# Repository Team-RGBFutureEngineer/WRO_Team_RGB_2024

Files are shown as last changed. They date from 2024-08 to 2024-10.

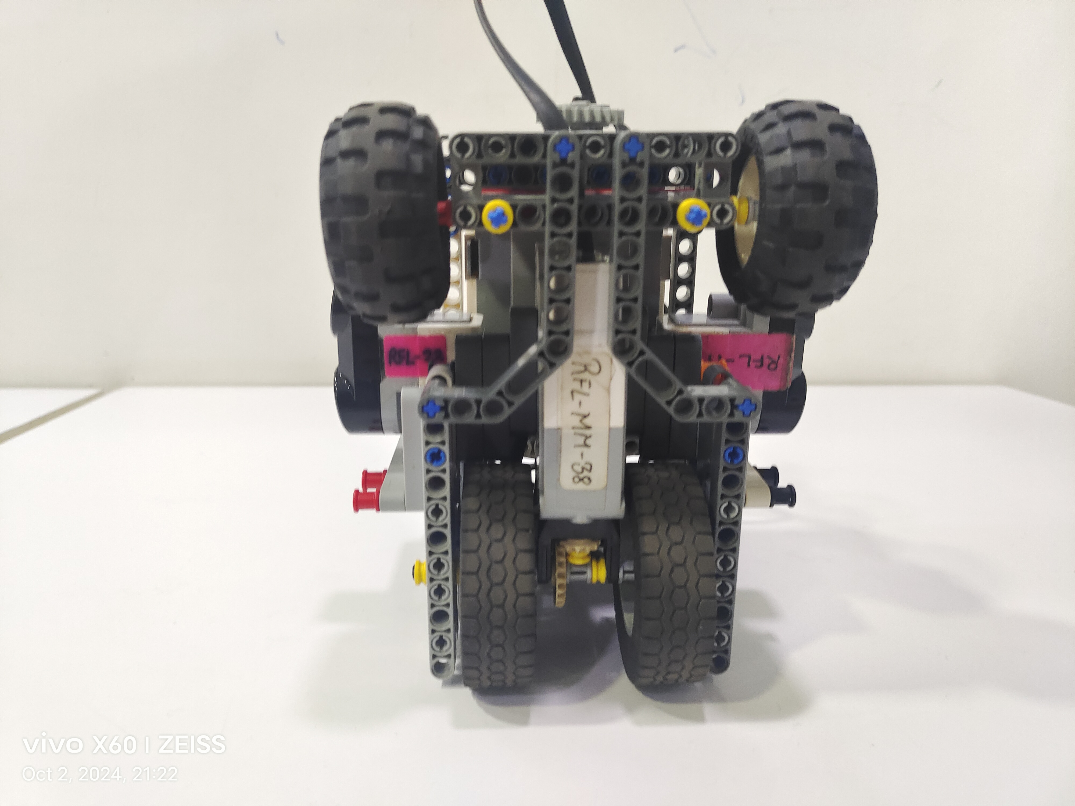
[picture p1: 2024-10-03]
v-photos/BOTTOM.jpg

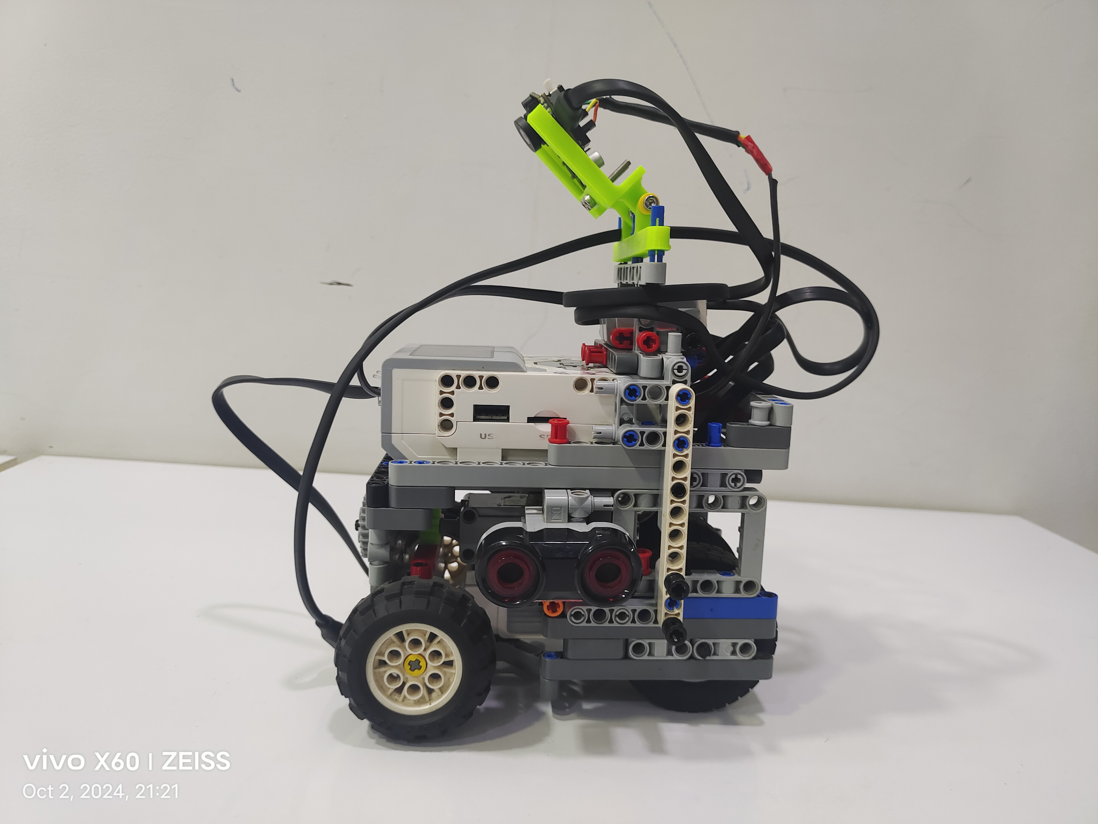
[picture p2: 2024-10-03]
v-photos/LEFT.jpg

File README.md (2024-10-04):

# Team RGB – WRO Future Engineers 2024

We are **Team RGB**, a duo of engineering students from **RFL Academy**, united by our passion for **Robotics**. We have clearly divided our roles to maximize our strengths:

**Bhavya Sanghrajka – Lead Programmer & Electronics**: Bhavya is responsible for the robot's programming and electronics systems. He specializes in developing advanced control algorithms, including PID control, and designing the logic that powers the robot’s movements and decision-making. Bhavya ensures the seamless integration of sensors and motors, programming the robot to execute precise maneuvers for both the open-round and obstacle-round. 

**Raj Kothari – Lead Designer & Constructor**: Raj is responsible for the structural and mechanical design of the robot. With a focus on precision and functionality, he uses CAD software to create a robust and lightweight design that adheres to the competition’s strict dimension and weight restrictions. Raj specializes in optimizing the integration of LEGO components with custom-designed parts, ensuring the robot performs reliably in both maneuverability and stability under competition conditions.

**Sahil Gajera - Mentor**:  A computer engineer by profession, Sahil sir is a robotics and linux enthusiast. His experience in First Robotics Competition (FRC) has helped us a lot in this entire joureny of Future Engineer category. 

# Construction Timeline

## First Iteration

Iteration 1

In the **Initial phase** of our design, we prioritized selecting lightweight yet durable components to ensure the robot maintained an optimal balance between strength and weight. Our first iteration featured a **3D-printed chassis** combined with a **steering mechanism** constructed from **LEGO parts**. However, this design presented several limitations, as the integration of the LEGO components with the 3D-printed chassis proved unreliable, and the overall structure became too bulky and heavy.

**Strengths**
- **Lightweight and Durable Focus** - Prioritizing lightweight yet durable components ensured that the robot had an optimal balance between strength and weight, which is essential for performance.
- **Customization Options** - Using a 3D-printed chassis allowed for high levels of customization, enabling us to explore innovative design possibilities.

**Weakness**
- **Structural Instability** - Integration of LEGO components with 3D-printed parts lacked mechanical stability, leading to weak points in the structure.
- **Bulky Design** - The overall structure became too bulky and heavy, which negated the initial focus on lightweight components.

**Opportunities**
- **Material Optimization** - Explore alternative 3D printing materials or geometries (e.g., honeycomb structures) to reduce weight without compromising durability.
- **Enhanced Modular Design** - Refining the integration of modular components (e.g., steering mechanisms) could improve adaptability and reduce structural issues in future iterations.

**Threats**
- **Performance Limitations** - The bulky and unreliable design could limit the robot’s performance, particularly in speed, maneuverability, and battery efficiency.
- **Time and Resource Constraints** - Continuous redesigns or modifications to address the weaknesses could impact project timelines and require additional resources.

## Second Iteration

Iteration 2

For the **Second iteration**, we transitioned to a **fully 3D-printed design**, including the steering mechanism. This solved many of the issues encountered in the previous version. The meshing of the **3D-printed gears** and steering components was precise. However, we faced challenges in aligning some parts during assembly, and reprinting components was **time-consuming** when adjustments were needed.

**Strengths**
- **Fully 3D-Printed Design** - Transitioning to a fully 3D-printed design, including the steering mechanism, resolved many integration issues from the previous iteration.
- **Precision in Gear Meshing** - Full control over gear design allowed for highly accurate meshing between 3D-printed gears and steering components, minimizing backlash and increasing mechanical efficiency.

**Weakness**
- **Assembly Complexity** - Alignment challenges arose during assembly, as 3D-printed components lacked built-in tolerances, making precise fitting of parts difficult.
- **Reprinting Delays** - Adjustments or design modifications required lengthy reprints, which increased downtime and reduced iteration speed.

**Opportunities**
- **Improved Assembly Process** - Refining the design for easier alignment during assembly could streamline the building process and reduce errors.
- **Iterative Refinement** - With continued iterations, the 3D-printed design could become more efficient and quicker to produce, especially by fine-tuning the parts for better fit.

**Threats**
- **Time Constraints** - The need to frequently reprint parts for adjustments could significantly impact project timelines, especially if iterations are slow.
- **Dimensional Inaccuracies** - Printer calibration or material expansion during cooling could lead to dimensional inaccuracies, affecting part performance and requiring reprints.

## Final Iteration

LEGO CAD

In the **Third iteration**, we opted for a **fully LEGO-based chassis**. Given that we had already achieved a precise gear mesh using custom **3D-printed gears and racks**, we integrated these components into the new design. The rear wheel motor relied on LEGO gears, while the steering mechanism utilized a custom 3D-printed gear perfectly matched with a custom 3D-printed rack, offering the best combination of customization and reliability.

**Strengths**
- **Fully 3D-Printed Design** - Transitioning to a fully 3D-printed design, including the steering mechanism, resolved many integration issues from the previous iteration.
- **Precision Gear Integration** - The combination of custom 3D-printed gears and racks with LEGO components resulted in highly precise gear meshing, minimizing mechanical losses and maximizing drive efficiency.

**Weakness**
- **Design Flexibility Limitations** - While the LEGO chassis offered modularity, it imposed constraints on component arrangement and customization compared to a fully 3D-printed or custom design.
- **Potential Compatibility Issues** - Integrating 3D-printed components with LEGO parts introduced potential alignment and mechanical fit challenges that could affect reliability over time.

**Opportunities**
- **Hybrid System Optimization** - Further optimization of the hybrid LEGO-3D printed design could lead to increased system robustness, combining the strengths of both approaches (e.g., modularity of LEGO, precision of custom parts).
- **Enhanced Design Modularity** - Expand modularity by developing interchangeable 3D-printed parts compatible with LEGO, facilitating quick upgrades or repairs without major redesigns.

**Threats**
- **Component Wear and Tear** - Over time, the wear on LEGO gears and 3D-printed parts could affect performance, requiring maintenance or replacement of key components.
- **Structural Limitations** - LEGO's inherent structural limitations could impact the robot's ability to handle heavy loads or more demanding tasks, potentially hindering further scaling or robustness improvements.

# Custom 3D Printed Parts
## Rack & Gear
rack
gear

We designed a **custom 7.2 cm rack** with a similar **groove** pattern and design as the standard **6.4 cm LEGO rack**. The original 6.4 cm LEGO rack had some problems wherein its shorter length made it difficult to mesh smoothly with the **20-tooth double bevel black LEGO gear**, which restricted the wheels from achieving specific steering angles.

However, even with our 7.2 cm rack, we encountered a minor issue: the grooves of the black LEGO gear and our custom rack weren’t perfectly meshing. While it functioned temporarily, the meshing wasn't ideal, and the **error compounded by 0.01 with each turn**. To overcome this, we also created a **custom 12 tooth gear** whose grooves are **perfectly meshing** with custom rack thus eliminating meshing errors and significantly improved the accuracy of the steering, allowing the wheels to turn at **precise angles**.

**Strengths**
- **Improved Rack Design** - The custom 7.2 cm rack, designed to replicate the LEGO rack's groove pattern, provided better meshing with the LEGO gear, reducing initial steering issues and improving maneuverability.
- **Enhanced Steering Precision** - The development of a custom 12-tooth gear that perfectly meshed with the custom rack eliminated alignment issues, significantly improving the steering accuracy and control.

**Weakness**
- **Initial Misalignment Issues** - Despite the improvement with the custom rack, the minor alignment issue between the grooves of the LEGO gear and custom rack introduced a small cumulative error (0.01 degrees), which reduced precision over time.
- **Complex Manufacturing** - The creation of custom racks and gears requires precision manufacturing (likely 3D printing), which can be time-consuming and requires access to specialized equipment for accurate results.

**Opportunities**
- **Optimized Custom Components** - Further refinement of custom components, such as varying tooth profiles or gear materials, could increase durability, precision, and overall performance in steering and navigation systems.

**Threats**
- **Component Wear and Tear** - Over time, custom 3D-printed components may wear down faster than standard LEGO parts, introducing alignment or meshing issues, which could degrade steering accuracy.
- **Component Compatibility** - Relying on custom gears and racks introduces the risk of incompatibility with other standard LEGO components, potentially limiting future upgrades or repairs using off-the-shelf LEGO parts.

## Pixy Mount & Beam
pixy mount and beam

During the robot’s journey, we encountered **instability with the Pixy camera**, which frequently shifted and struggled to accurately detect objects. To address this issue and secure the Pixy at a precise angle, we 3D-printed two custom components.

First, we created a **custom beam** that perfectly aligned with the **holes of the H-frame**, enabling us to securely attach the Pixy to the connector. Additionally, we designed a **custom mount** to provide further support and stability for the Pixy camera.

Both the beam and the Pixy mount were connected using **3 mm screws**, allowing for easy adjustment and locking of the camera at the **desired angle**. This setup ensured that the Pixy could consistently scan and detect objects with accuracy, especially during the obstacle round challenge.

**Strengths**
- **Improved Camera Stability** - The custom 3D-printed beam and mount provided secure, adjustable positioning for the Pixy camera, ensuring accurate object detection and eliminating the instability encountered during movement.
- **Precise Alignment** - The beam design was tailored to align perfectly with the holes of the H-frame, facilitating a secure connection and stable support for the Pixy, improving its performance during the obstacle challenge.

**Weakness**
- **Complex Assembly** - The custom setup, involving 3 mm screws and custom components, added complexity to the assembly process and may require careful calibration to achieve the optimal camera angle.
- **Potential Adjustability Limitations** - While the camera can be adjusted, any significant design changes in future iterations may require reprinting the custom components, introducing delays in development.

**Opportunities**
- **Modular Design Improvements** - Refining the 3D-printed mount and beam to be modular or flexible could allow for easier adjustments, enabling the camera to adapt to different angles or robot configurations.
- **Enhanced Object Detection** - The secure and precise positioning of the Pixy camera opens the possibility for improved computer vision or AI-driven detection algorithms, leading to better object recognition and navigation accuracy.

**Threats**
- **Component Durability** - Over time, the 3D-printed beam and mount may experience wear, especially if frequent adjustments are made, potentially leading to loosening or misalignment that affects detection accuracy.

## Our Robot

lego with dimensions

Our robot measures **16.5 cm in length, 16 cm in width, and 24 cm in height**, with a total weight of **0.9 kg**. It is powered by **two medium motors**—one dedicated to driving the rear wheels and the other for controlling the steering mechanism. The rear wheels (62.4 x 20s) are mounted on a **single axle** and connected to the motor via LEGO gears. The steering wheels (62.3 x 21s) are also mounted on a single axle and connected to the motor, with the steering system operating through the custom 3D-printed gear and rack, ensuring smooth and precise movement.

The robot is equipped with two **LEGO ultrasonic sensors**, mounted on both left & right side, and a **gyro sensor** placed on top for navigation. For obstacle detection, we integrated a **Pixy 2.1 camera**. The entire system is powered by a **LEGO Mindstorms EV3 brick**, which manages the control and coordination of the sensors and motors. 

- **Turning Radius of our robot is 75 degree**
- **Centre Distance between both wheels is 11 cm** 

# Electricals 

Robot Schematic

This diagram illustrates the wiring and components configuration of our robot 

### Central Unit
EV3 Brick
### Input Ports (1-4)
- **Port 1: Left LEGO Ultrasonic Sensor**
- **Port 2: Right LEGO Ultrasonic Sensor**
- **Port 3: Gyro Sensor**
- **Port 4: Pixy Camera**
### Output Ports (A-D)
- **Port A: Rear Wheel Motor**
- **Port B: Steering Wheel Motor**

# Power Management

LEGO DC BATTERY

This is our 2050 mA DC Rechargeable Battery which provides power to the EV3 Brick and other components. Here's an estimated power consumption breakdown for each component:

**1. LEGO Ultrasonic Sensor:**
- Current Consumption: Approximately **20 mA**
- Power Consumption: Approximately **0.2W**

**2. LEGO Medium Motor:**
- Current Consumption: Between **100-150 mA** 
- Power Consumption: Approximately **1.25W**
  
**3. LEGO Gyro Sensor:**
- Current Consumption: Approximately **10-15 mA**
- Power Consumption: Approximately **0.15W**
  
**4. LEGO EV3 Brick:**
- Current Consumption: Between **150-250 mA**
- Power Consumption: Approximately **2W**
  
**5. Pixy 2.1 Camera:**
- Current Consumption: Approximately **140 mA**
- Power Consumption: Approximately **1.4W**

graph

# Components

Our bot consists of the following components:
- LEGO Mindstorm EV3 Brick
- LEGO Rechargeable DC Battery
- EV3 Medium Servo Motor
- LEGO Ultrasonic Sensors
- LEGO Gyro Sensor
- PIXY 2.1 Camera
- Lego Cables
- Russian Wheels
- Steering Wheels
### 1. LEGO Mindstorm EV3 Brick
The EV3 Brick is the central control unit of our robot. It features a programmable interface with a display screen and buttons for manual control. It is programmed using LEGO's Mindstorm software. It has 4 ports for Input and output, currently, our bot uses 2 output ports for both medium motors and 3 input ports for 2 ultrasonic sensors and gyro sensors.

### 2. LEGO Rechargeable DC Battery
This 2000 mAh battery provides power to the EV3 Brick and other components. It is rechargeable and designed to fit into the EV3 Brick.

### 3. EV3 Medium Servo Motor
The medium servo motor is used for precise movements and rotations. It is smaller in size compared to the large motor and is capable of rotating 360 degrees with precise angle control, useful for the steering mechanism.

### 4. LEGO Ultrasonic Sensors
The sensors are mounted on both sides of the robot to accurately measure the proximity to adjacent walls. The sensor then measures the round-trip time for the reflected waves to return. By calculating the time interval between emission and reception, the sensor determines the distance between the robot and the wall using the speed of sound in air as a constant.

### 5. LEGO Gyro Sensor
The sensor is mounted on the top of the robot, it enables precise control over the robot's orientation adjustments and stability by detecting minute changes in angular displacement. It plays an essential role in trajectory tracking by calculating and storing the robot’s initial position. Over the course of three laps, the gyro ensures that the robot consistently returns to its starting position.

### 6. Pixy 2.1 Camera
The PIXY 2.1 Camera is an advanced vision sensor that can detect and track objects based on color. It provides real-time image processing capabilities and is used for object detection in obstacle challenge.

### 7. LEGO Cables
These cables help in building connections between motors, and sensors to the EV3 Brick. They are responsible for transmitting power and data between the components and EV3 Brick.

### 8. LEGO Russian Wheels (62.4 x 20)
These wheels are used as rear wheels in our robot. These wheels are 62.4 mm in diameter and 20 mm in width.

### 9. LEGO Tractor Wheels (56 x 26)
These wheels are used as front wheels in our robot. These wheels are 56 mm in diameter and 26 mm in width.

# Programming Timeline
During the initial two iterations of our robot, we utilized a 3D-printed chassis to allow for greater customization and explore new design possibilities. For processing and control, we opted to use a Raspberry Pi, despite it being our first time working with this platform, including its schematics and programming interface.

To streamline our workflow, we researched methods for accessing and controlling the **Raspberry Pi** without the need for external peripherals like a monitor or keyboard. We initially implemented **RealVNC Viewer**, a software solution that enabled remote access to the Raspberry Pi from the development computer. However, we soon encountered performance limitations, as the virtual environment proved to be too laggy, negatively impacting the overall user experience and efficiency.

Later, we discovered that by utilizing OBS Studio in conjunction with an HDMI Input to Output converter, we could display the Raspberry Pi's interface on a primary monitor, enabling direct editing in the main window. As we were new to working with the Raspberry Pi, initially, gathering resources and compiling the necessary code posed a significant challenge. Several features required extensive installation and configuration, further complicating the process.

After over **30 days of working with the Raspberry Pi**, we identified opportunities to enhance system performance by incorporating an **Arduino board**. This allowed us to optimize the robot's functionality by distributing tasks between the **Arduino and the Raspberry Pi**, which successfully met our performance objectives.

However, due to structural constraints and the limited available space for components, wiring, and the power distribution board, we faced difficulties fitting everything within the robot’s designated size restrictions. Following a comprehensive evaluation of both the construction and programming challenges, we collectively decided to transition to the **LEGO EV3** system. Our prior familiarity with these components enabled a smoother transition, allowing us to work more efficiently. With the **EV3 Mindstorms platform** and the **PixyCam**, which is compatible with the EV3, we achieved greater efficiency compared to the Raspberry Pi setup. The LEGO system also provided the flexibility to easily modify and customize the robot’s design to suit our needs.

## Open Round Challenge

OpenRound_Flowchart

The robot’s journey begins by determining which direction it should turn over the course of the next **3 laps**. To achieve this, we rely on **Ultrasonic Sensors** mounted on both sides of the robot to detect the absence of walls.

As the robot approaches a potential **turning point**, it calculates the average of the sensor readings. The robot continues moving forward as long as this average remains below 80, which indicates that walls are detected on both sides. During this phase, the **Gyro Sensor** ensures that the robot maintains a **straight path**.

When the sensor reading exceeds 80, this indicates that a wall is missing on one side. At this point, the robot checks whether the **UltrasonicLeft** reading is greater than 100. If this condition is met, the robot initiates a left turn. Otherwise, it performs a right turn.

The turns are executed with the assistance of the **Gyro Sensor**, providing increased accuracy during the maneuver.

Once the direction is determined, the robot continues moving forward under **Gyro PID control** until the relevant sensor (for example, if a left turn was initiated, the UltrasonicLeft sensor) detects the presence of a wall again. When the wall is no longer detected, the robot completes the turn.

To track the robot’s progress, a **counter** is incremented by one with each turn. When the counter reaches 12, indicating that three laps have been completed, the robot stops.

**_Description of blocks are given in the sections later_**

### Challenges Faced

- **Inaccurate Turn Detection with Ultrasonic Sensors** - We encountered difficulties in detecting turns accurately due to the ultrasonic sensors occasionally providing false or inconsistent readings. 
- **Maintaining a Straight Path Using Gyro PID** - Keeping the robot moving straight using Gyro PID control was challenging, especially when small disturbances caused the robot to drift.

### Resolutions

- We improved sensor accuracy by **filtering out** erratic values using an **averaging** method or by setting specific **thresholds** to disregard outliers. This helped the robot make more consistent decisions about when to turn.
- We tuned the **PID values** carefully to minimize drift and oscillations, ensuring the robot maintained a **stable straight path** over the course of the laps.

## Obstacle Round

OBSTACLE ROUND FLOWCHART

The robot’s journey begins with checking Ultrasonic Sensor’s readings for deciding what turn to take. Once that is decided the code for taking respective turns starts.

The **Pixy Camera** connected to the Ev3 constantly keeps checking if any block **(Green or Red is detected)**. If yes, then it moves closer to the block until its area is above 2000 (Area is calculated by multiplying the length &  width of the block. 
If the block is RED --> Take a Right Turn
If the block is Green --> Take a Left Turn

With every operation a separate loop of checking the Blue lines and Orange lines is checked. If at the start it was decided that the robot will take a Left turn then the Blue line is checked and vice verse.
When the line is detected the robot takes a **Gyro based** 90 degree turn.

At the end of 7 turns, the robot keeps on detecting the elements and the values of them are stored in an array. After the 8th turn **the robot decides if it has to take a U-Turn or not** based on the last block which is Red or Green.

Later the 4 rounds are completed and the robot gets into the search of parking that is of color Magenta. After following it using the **encoder** values of the motor we have tried to park the robot fully inside the provided parking area.

### Challenges Faced

- **Turning Without Collisions** - While making turns to avoid obstacles, we struggled to prevent the robot from colliding with objects or walls, as its turns were not always smooth or precise.
- **U-turn Logic and Block Detection** - Detecting blocks accurately for U-turn decisions posed difficulties. At times, the camera struggled to recognize blocks, leading to inconsistent U-turn execution.

### Resolutions

- We refined the **robot's turn logic**, adjusting the speed and timing of the turns to give it enough clearance from obstacles. We also used the **Gyro Sensor** to ensure smoother and more controlled turns.
We improved the **Pixy Camera’s** block detection by **fine-tuning** the camera’s **sensitivity** and ensuring the block's area was correctly calculated. This allowed the robot to make reliable **U-turn** decisions based on the **detected block color**.

## Pixy Camera Detection

The Pixy camera utilizes color-based object detection and assigns specific identifiers based on the detected object's color and type. The classification scheme operates as follows:

### 1. Blocks:
greendetect

- **Green** - Represented as **'G'**, these objects are recognized as blocks with a green hue.

reddetect

- **Red** - Represented as **'R'**, these objects are recognized as blocks with a red hue.
  
### 2. Lines:
OrangeDetect

- **Orange** - Represented as **'O'**, these objects are identified as lines with an orange hue.
BlueDetect

- **Blue** - Represented as **'B'**, these objects are identified as lines with a blue hue.

### 3. Parking Wall:
parkingDetect

- **Magenta** - Represented as **'M'**, this object type indicates a parking wall with a magenta hue.

## Blocks Description

**Gyro PID**: This block is responsible to keep the robot driving straight with respect to the gyro sensor’s value.  The calculation goes as follows:
Gyro Sensor’s current reading – Threshold value(set by the user)  = Current Error
Current Error * 0.8 = kp (The value 0.8 needs to be tuned with respect to each robot)
(Current Error – Previous Error) * 0.5 = kd (The value 0.8 needs to be tuned with respect to each robot)
Kp + kd = final_value (This value needs to be passed to the Steering motor’s power)
Assign the previous value as the current error for the next loop
(previous_error = current_error)

gyro pid

**GyroTurnLeft or GyroTurnRight**: This block is used to ensure that the robot turns a specific angle that is the required target position
Here the current value of Gyro sensor is noted.
Turn and Steering motor and keep the drive motor ON until the gyro sensor’s value is not greater than the target value
Run this in a loop
Make the steering motor back to its original position 
(Motor Encoder value * -1) is given to the motor’s target position to bring the steering motor back to its original position

gyro left

**Obstacle Sense:** Here we calculate how much the robot has to turn and return to its value for passing an obstacle (red or green)
Read the values of the detected object, Multiply the height and width of object to check how near it is to the robot
When it is near to the robot, take a turn and drive the motor until **The camera cannot see the block**
Return the Steering motor to its original positon and keep moving ahead

obstacle sense

**Ultrasonic Sensor Wall Follow PID**: This block is responsible to keep the robot driving straight with respect to the deviation of the robot from both the side walls.  We’ll be using 2 sensors, 1 on left and the other on right for better accuracy. The calculation goes as follows:
Left Ultrasonic Sensor’s current reading – Right Ultrasonic Sensor’s current reading  = Current Error
(Current Error – Previous Error) * 0.5 = magnified final value (The value 0.5 needs to be tuned with respect to each robot)
This final value needs to be passed to the Steering motor’s power
Assign the previous error value as the current error value

wall follow pid

## Conclusion

The robot's construction and programming are optimized for high precision and efficiency, tailored to meet the requirements of both the Open Round and Obstacle Round challenges. 

### Construction

The robot’s compact size **(16.5 cm x 16 cm x 24 cm) and light weight (0.9 kg)** ensure a balance of agility and stability. Powered by two medium LEGO motors, it controls rear-wheel propulsion and steering through a custom 3D-printed gear and rack system. Equipped with LEGO ultrasonic sensors, a gyro sensor, and a Pixy 2.1 camera, the robot effectively detects obstacles and navigates the course, including parking walls, with precision.

### Open Round Challenge

In the Open Round, the program uses Ultrasonic Sensors and Gyro PID control to maintain alignment and execute precise turns. The robot detects missing walls **(sensor reading >80)** and turns left or right based on sensor data. With the Gyro sensor ensuring accuracy, the robot completes **12 turns over 3 laps in 65 seconds**, efficiently navigating using optimized sensor feedback.

### Obstacle Round Challenge

In the Obstacle Round, the Pixy 2.1 camera detects colored blocks and lines, prompting the robot to turn based on the block color **(right for red, left for green)**. It continuously checks for blue or orange lines to adjust its direction, storing detected data in an array to guide decisions, including **U-turns after 8 turns**. The round concludes with the robot searching for a magenta parking area and using motor encoder values to park precisely. The entire Obstacle Round, **including parking, is completed in 140 seconds.**

# Video Links
## Link Tree
https://linktr.ee/rgbfe2024
## Open Round Challenge
**Youtube** - https://youtu.be/_w3JlFxCa_E?si=RLct2GLcysBRvsGL
## Obstacle Round Challenge
**Youtube** - https://youtu.be/dA7stuY_RsI

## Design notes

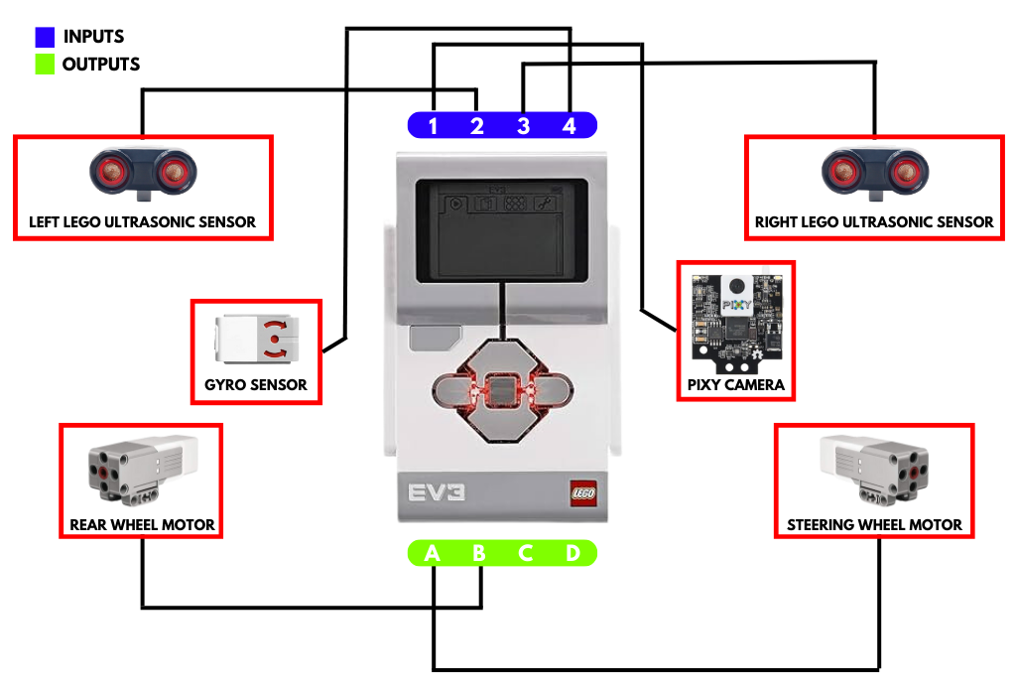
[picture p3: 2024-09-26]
Schematic/Robot Schematic.png

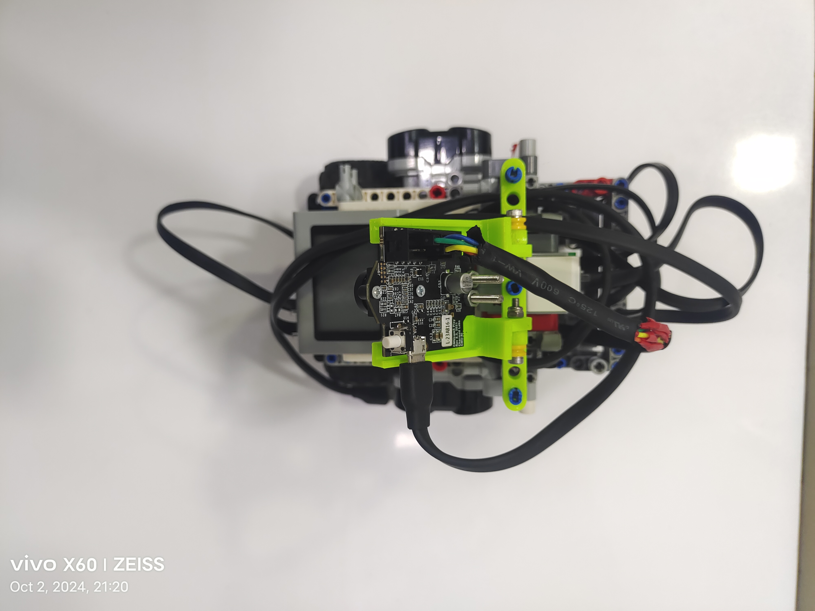
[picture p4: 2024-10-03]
v-photos/TOP.jpg

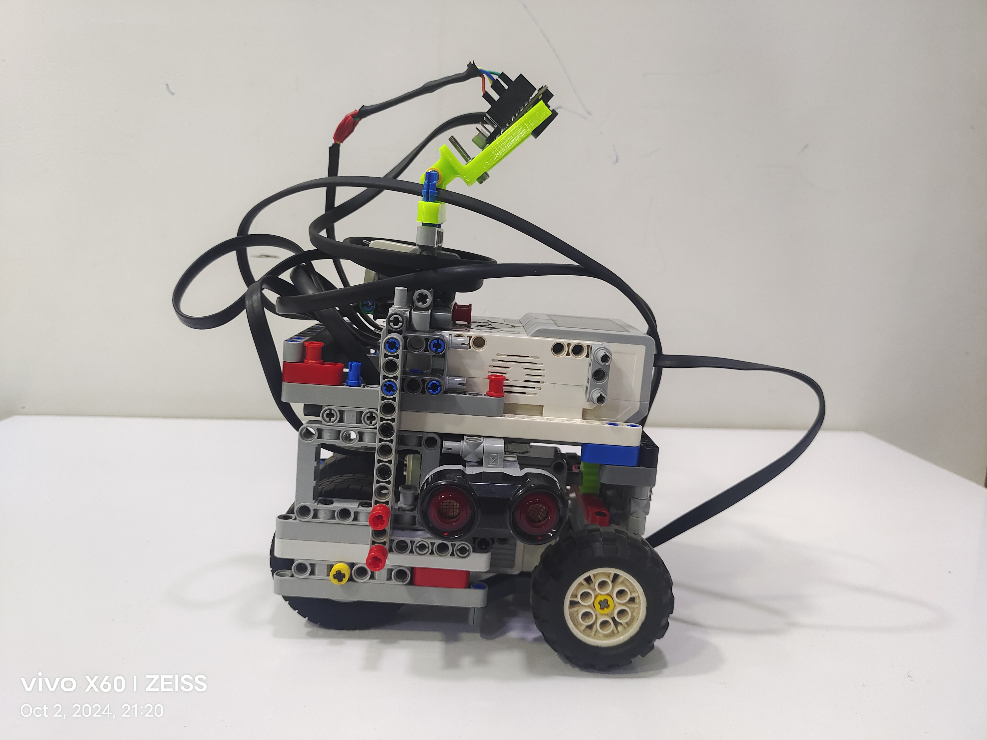
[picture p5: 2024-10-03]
v-photos/RIGHT.jpg

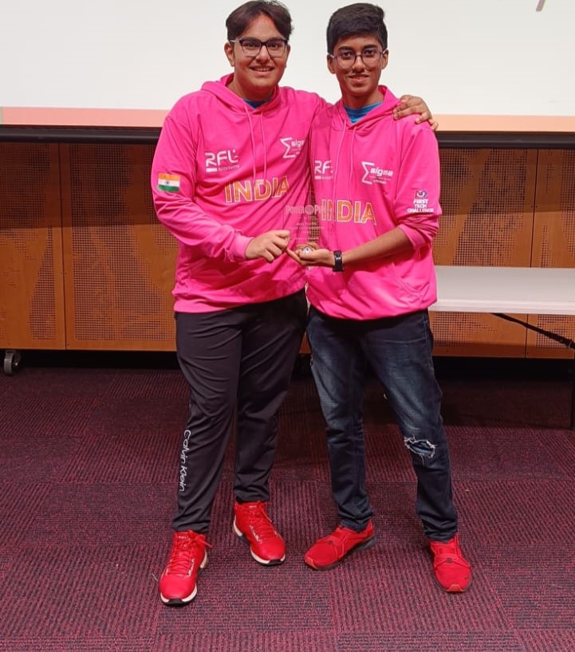
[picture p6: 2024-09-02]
t-photos/TeamPhotoRGB.jpg

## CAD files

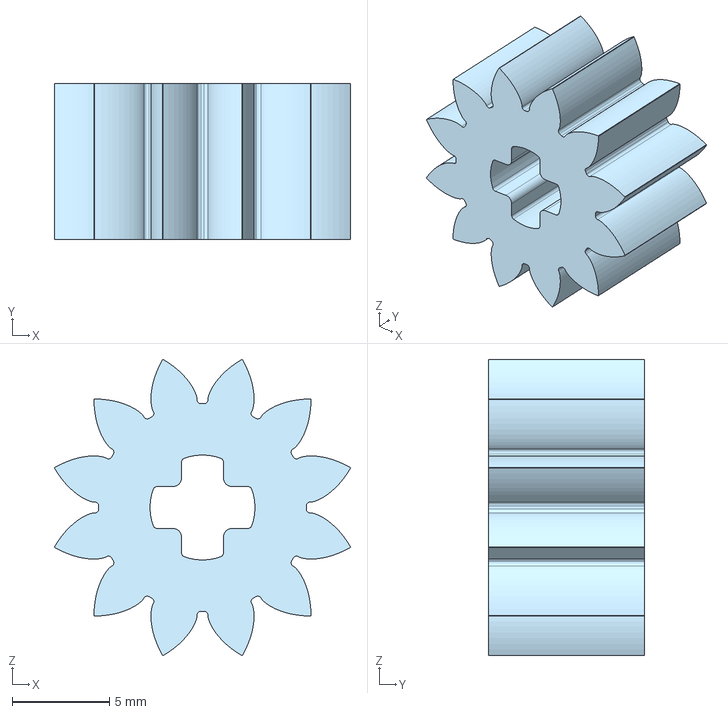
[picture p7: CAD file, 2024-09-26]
Robot CAD/Custom Gear.step
15.2 x 8.00 x 15.2 mm

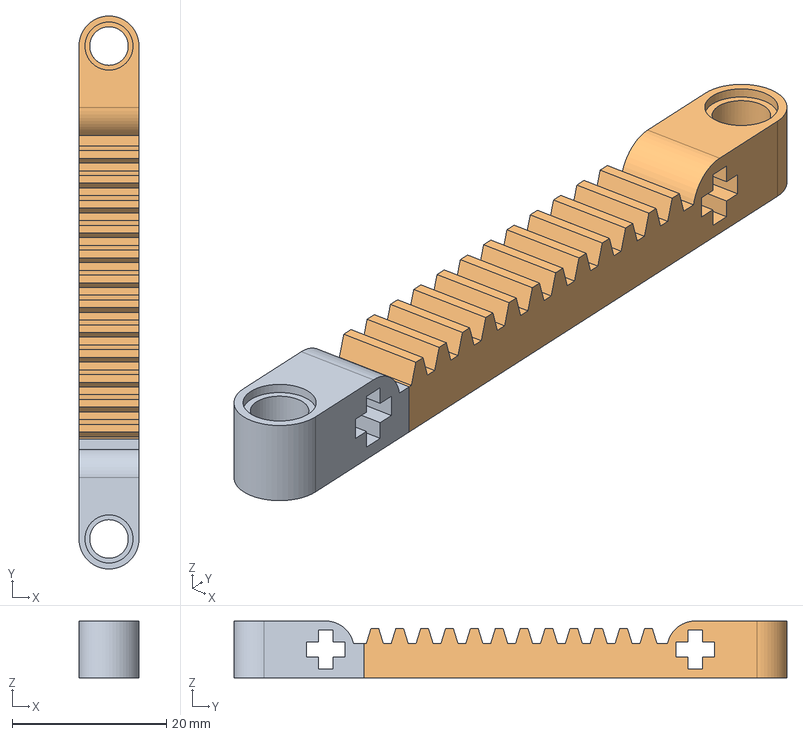
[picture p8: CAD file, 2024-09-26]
Robot CAD/Custom Rack.step
7.80 x 71.8 x 7.40 mm
64781 Technic, Gear Rack 1 x 13 with Axle and Pin Holes v7 x 2

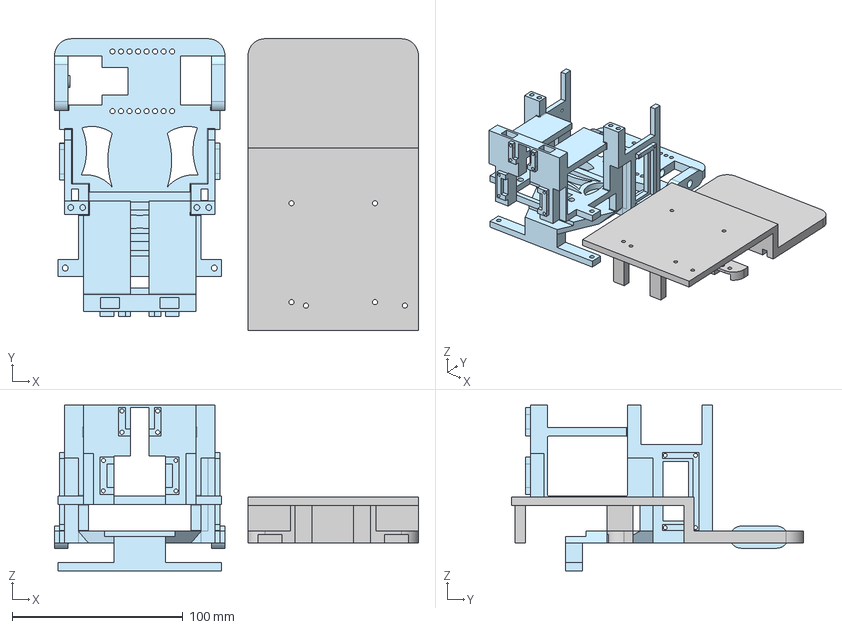
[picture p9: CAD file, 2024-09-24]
Robot CAD/IT2.step
213.5 x 171.0 x 97.3 mm

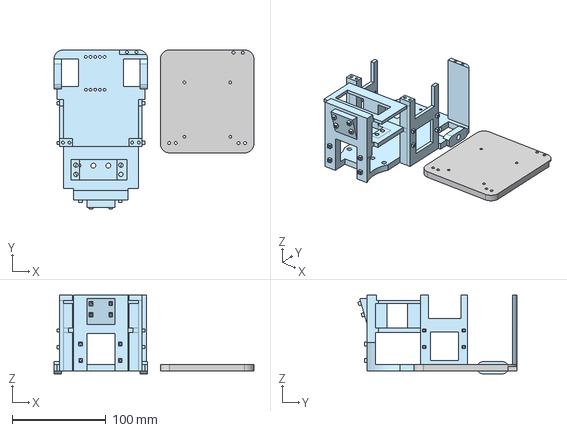
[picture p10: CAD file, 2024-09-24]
Robot CAD/IT1.step
213.5 x 170.0 x 84.0 mm

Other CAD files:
Robot CAD/Custom Gear.stl
Robot CAD/Custom Rack.stl
Robot CAD/IT1.stl
Robot CAD/IT2.stl

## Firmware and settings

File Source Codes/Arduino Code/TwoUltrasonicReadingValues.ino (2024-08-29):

//Ultrasonic Sensor with Serial Monitor
int trigger1 = 8;//r
int echo1 = 9;
int trigger2 = 10;//l
int echo2 = 11;
int trigger3 = 12;//f
int echo3 = 13;

float distance1 = 0;
float distance2 = 0;
float distance3 = 0;
float count3 = 0;
float count1 = 0;
float count2 = 0;

void setup() 
{
  pinMode(trigger1, OUTPUT);
  pinMode(echo1, INPUT);
  pinMode(trigger2, OUTPUT);
  pinMode(echo2, INPUT);
  pinMode(trigger3,OUTPUT);
  pinMode(echo3,INPUT);
  Serial.begin(9600);
}

void loop()
{
  // Sensor 1 right
//  digitalWrite(trigger1, LOW);
//  delayMicroseconds(100);
//  digitalWrite(trigger1, HIGH);
//  delayMicroseconds(100);
//  digitalWrite(trigger1, LOW);
//  count1 = pulseIn(echo1, HIGH);
//  distance1 = count1 * 0.01715;

//   Sensor 2 left
  digitalWrite(trigger2, LOW);
  delayMicroseconds(30);
  digitalWrite(trigger2, HIGH);
  delayMicroseconds(10);
  digitalWrite(trigger2, LOW);
  count2 = pulseIn(echo2, HIGH);
  distance2 = count2 * 0.01715;

//  //sensor 3 center
//  digitalWrite(trigger3, LOW);
//  delayMicroseconds(10);
//  digitalWrite(trigger3, HIGH);
//  delayMicroseconds(10);
//  digitalWrite(trigger3, LOW);
//  count3 = pulseIn(echo3, HIGH);
//  distance3 = count3 * 0.01715;

  // Send both distances via Serial

  Serial.println(distance2);


}

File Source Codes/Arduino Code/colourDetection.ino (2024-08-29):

//Reading Values of Colors
// Pin definitions
const int S0 = 4;   // S0 pin
const int S1 = 5;   // S1 pin
const int S2 = 6;   // S2 pin
const int S3 = 7;   // S3 pin
const int sensorOut = 8; // OUT pin

// Variables to store frequency values for each color
unsigned long redFrequency = 0;
unsigned long greenFrequency = 0;
unsigned long blueFrequency = 0;

void setup() {
  // Set the control pins as outputs
  pinMode(S0, OUTPUT);
  pinMode(S1, OUTPUT);
  pinMode(S2, OUTPUT);
  pinMode(S3, OUTPUT);

  // Set the sensor output as input
  pinMode(sensorOut, INPUT);

  // Set frequency scaling to 20% (S0 HIGH, S1 LOW)
  digitalWrite(S0, HIGH);
  digitalWrite(S1, LOW);

  // Start serial communication for debugging
  Serial.begin(9600);
}

void loop() {
  // Set S2 and S3 to read red frequency
  digitalWrite(S2, LOW);
  digitalWrite(S3, LOW);
  redFrequency = pulseIn(sensorOut, LOW);
  delay(100); // Add a small delay to stabilize readings

  // Set S2 and S3 to read green frequency
  digitalWrite(S2, HIGH);
  digitalWrite(S3, HIGH);
  greenFrequency = pulseIn(sensorOut, LOW);
  delay(100); // Add a small delay to stabilize readings

  // Set S2 and S3 to read blue frequency
  digitalWrite(S2, LOW);
  digitalWrite(S3, HIGH);
  blueFrequency = pulseIn(sensorOut, LOW);
  delay(100); // Add a small delay to stabilize readings

  if(redFrequency>120 && blueFrequency<210 && greenFrequency<200)
  {
    Serial.println("Green Detected");
  }
  else if(redFrequency<120 && blueFrequency>175 && greenFrequency>210)
  {
    Serial.println("Red Detected");
  }
  else if(redFrequency>220 && blueFrequency<220 && greenFrequency>275)
  {
    Serial.println("Blue Detected");
  }
  else
  {
    Serial.println("Place Object");
  }

  // Add a delay between readings
  delay(500);
}
                                                                        

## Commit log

2024-08-29 Create arduino
2024-08-29 Create Arduino Codes
2024-09-02 Create Circuit Diagrams
2024-09-24 Iteration 1
    [IT1.step]
2024-09-24 Iteration 2
    [IT2.step]
2024-09-25 Iteration 1 Step file
    [IT1.step]
2024-09-26 Iteration 2 STEP File
    [IT2.step]
2024-09-26 Custom Rack Step File
    [Custom Rack.step]
2024-09-26 Custom Gear STEP File
    [Custom Gear.step]
2024-09-26 Custom Rack STL File
    [Custom Rack.stl]
2024-09-26 Custom Gear STL File
    [Custom Gear.stl]
2024-09-26 Iteration 1 STL File
    [IT1.stl]
2024-09-26 Iteration 2 STL File
    [IT2.stl]
2024-09-26 EV3 Wiring Schematic
